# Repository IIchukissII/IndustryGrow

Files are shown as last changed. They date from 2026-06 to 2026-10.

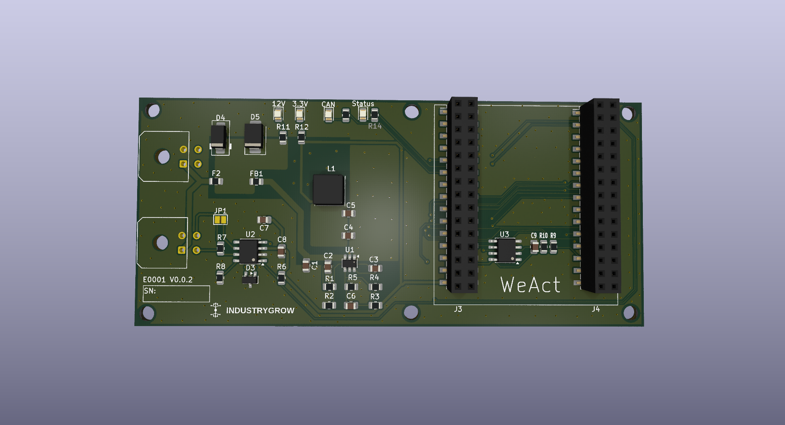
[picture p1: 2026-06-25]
store/E0001-000003-D.png

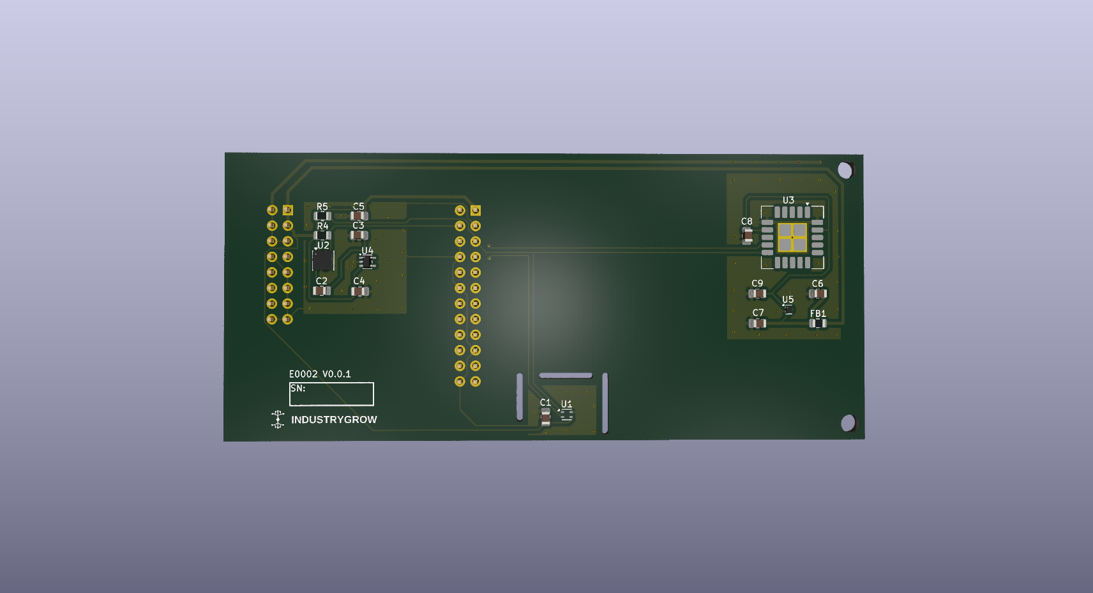
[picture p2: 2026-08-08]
store/E0002-000001-D.png

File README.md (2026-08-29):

<!--
SPDX-FileCopyrightText: 2026 The IndustryGrow contributors
SPDX-License-Identifier: CC-BY-SA-4.0
-->

<picture>
  <source media="(prefers-color-scheme: dark)" srcset="img/industrygrow-logo-mono-dark.svg" />
  IndustryGrow
</picture>

# IndustryGrow



Open-core field hardware, firmware and edge software for instrumented, profile-driven crop
cultivation. One architecture, from a cabinet to a several-hundred-square-metre facility. The
companion platform **IndustryFlow** stores history, runs analytics and distributes profiles.

Scope and rationale: [`MOTIVATION.md`](MOTIVATION.md), [ADR-0001](ADR/ADR-0001-industrygrow-framing.md).

## Architecture constraints

| Constraint | Record |
|---|---|
| Scaling multiplies node *instances* across zones. It adds no node classes. | ADR-0014 d2 |
| A signed, versioned JSON cultivation profile is the only channel that changes deployment behaviour. There is no remote-command API and no real-time tuning channel. | ADR-0015 d1, ADR-0025 |
| The gateway runs control loops locally against a cached profile. The cloud supplies profiles and observes; it does not command in real time. | ADR-0015 d8, ADR-0004 rev 1 |
| The over-temperature trip is analog, MCU- and bus-independent, and sits at the heating actuator. Profiles set operating parameters; hardware sets survival parameters. | ADR-0018 d10 |
| Sensor density is a deployment phase, not a fixture: dense during the empirical survey, reduced for the operating phase. The profile carries the identified model with the setpoints. | ADR-0016 |

## Technology

| Layer | Choice |
|---|---|
| Field bus | Cyphal over classic CAN @ 500 kbit/s, linear topology |
| Smart-node MCU | WeAct STM32F4 64-pin core board (STM32F405RGT6; F412/F446 drop-in) |
| Node carrier PCB | Custom integration board: CAN transceiver, ATECC608 secure element, two-header sensor-module interface |
| Node firmware | Embedded C with libcanard. One application holds every module personality; the module-ID strap selects at boot |
| Node flash layout | Bootloader at the reset vector plus the application in one of two slots; build output is `igrowboot.hex`, `igrow-a.hex`, `igrow-b.hex` |
| Firmware update | Signed image served over the bus, `uavcan.file.Read` to the slot that is not running, trial boot with fallback |
| Gateway | Raspberry Pi (3B+ minimum, 4/5 for higher traffic) + isolated 2-channel CAN HAT |
| Gateway software | Python / asyncio, SocketCAN + Pycyphal + Nunavut-generated DSDL bindings |
| Cloud link | mTLS to IndustryFlow; stateless edge in steady state, with a bounded local store for buffering and survey |
| Identity | Module class from the ID strap, `unique_id` from the ATECC608, Node-ID from a carrier-resident store; 127 = unprovisioned |
| Security | Operator CA, signed firmware, signed profiles |

Governing records: ADR-0002 rev 3 (bus, carrier, gateway), ADR-0005 (DSDL), ADR-0020
(persistence), ADR-0027 (identity), ADR-0029 (update and bootloader), ADR-0024 / ADR-0025 (CA,
profile signing).

> PCBs are authored in **KiCad 10** and will not open in earlier versions; cabinet distribution
> schematics (`E0007`) use **QElectroTech**. Design files live in `store/` under the ADR-0017
> scheme, packaged per document layer as `Exxxx-VVVVVV-S-src.zip` / `-D-src.zip` (d19).
> [`CONTRIBUTING.md`](CONTRIBUTING.md) has the unpack/repack procedure.

## Hardware

Seven sensor-module classes (M01–M07), one functional subsystem each, on the universal carrier
`E0001`, in the cabinet distribution case `E0007`. Instances of one design are specialized by
populated BOM, never by new designs; a functional group fitted or omitted at build is a populate
variant with its own assembly E-number (ADR-0017 rev 2 d4).

E-numbers, sensor complement, module-ID straps, variant rules and per-design state:
[`REGISTRY.md`](REGISTRY.md).

## Status

Phase 1 is data collection only, no actuators; it ends at stage 4, full cabinet telemetry from
M01–M05. Stage sequencing, dependencies, the Phase 1 → Phase 2 boundary and the v1.0 exit
criteria: [`project/ROADMAP.md`](project/ROADMAP.md), 14 dependency-ordered stages.

## Repository

| Path | Contents | Records |
|---|---|---|
| [`ADR/`](ADR/) | Architecture decision records — the source of truth — plus [`GLOSSARY.md`](ADR/GLOSSARY.md) | ADR-0000 |
| [`REGISTRY.md`](REGISTRY.md) | E-number / SP-number identifier map, machine-readable | ADR-0017, ADR-0019, ADR-0023 |
| [`store/`](store/) | Hardware design sources, fab packages and firmware release artifacts, flat, keyed by identifier | ADR-0017 |
| [`spec/`](spec/) | Module specifications — M01, M02, M05, M06, M07. M03 and M04 not yet written | ADR-0014 |
| [`firmware/`](firmware/) | Node firmware (C, libcanard) and the `industryflow.greenhouse` DSDL vocabulary | ADR-0005, ADR-0029 |
| [`gateway/`](gateway/) | Gateway provisioning, hardening, identity and profile-pull client | ADR-0004, ADR-0015 |
| [`erp/`](erp/) | Instance-and-integration ERP — the pre-cloud system of record | ADR-0021, ADR-0022 |
| [`pki/`](pki/) | Operator CA bootstrap and root-key ceremony | ADR-0024 |
| [`signing/`](signing/) | Profile signing tool and runbook | ADR-0025 |
| [`profiles/`](profiles/) | Cultivation profile instances | ADR-0003 |
| [`project/`](project/) | `ROADMAP.md` stage plan, `RESEARCH.md` open directions L1–L7 | — |
| [`MOTIVATION.md`](MOTIVATION.md) | The gap this project closes | — |
| [`CONTRIBUTING.md`](CONTRIBUTING.md) | Contribution licensing, DCO sign-off, working with the store | — |

## Build and run

Firmware — three images, ARM cross-toolchain and Ninja required:

```sh
firmware/tools/bootstrap.sh            # pin submodules; needs nnvg (Nunavut)
cmake -S firmware -B firmware/build -G Ninja \
      -DCMAKE_MAKE_PROGRAM="$(command -v ninja)" \
      -DCMAKE_TOOLCHAIN_FILE="$PWD/firmware/cmake/arm-none-eabi.cmake"
cmake --build firmware/build
```

ERP — application plus operator console:

```sh
cd erp && docker compose up --build    # app on 127.0.0.1:8021
```

Gateway — runs on the Pi, post-first-boot, idempotent:

```sh
sudo ./provision.sh                    # from the staged gateway/ bundle
```

Per-component detail, flashing procedure and signing keys are in each directory's `README.md`.

## Licensing

Open-core, licensed per part of the repository. [`LICENSE.md`](LICENSE.md) is the authoritative
mapping — hardware designs, documentation, application code and the DSDL protocol layer carry four
different licences, and directory-level assumptions do not hold. Full texts are in
[`LICENSES/`](LICENSES/).

Third-party content keeps its own terms, annotated in [`REUSE.toml`](REUSE.toml): the WeAct
core-board snapshot is published with **no licence stated**, so it is not covered by this project's
licences. Compliance is CI-enforced — run `reuse lint` before opening a pull request.

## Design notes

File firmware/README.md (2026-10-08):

<!--
SPDX-FileCopyrightText: 2026 The IndustryGrow contributors
SPDX-License-Identifier: CC-BY-SA-4.0
-->

# IndustryGrow node firmware

Firmware for the IndustryGrow Cyphal/CAN sensor nodes. One codebase, one carrier (`E0001`), one
MCU (STM32F405RGT6 on a WeAct STM32F4 64-Pin Core Board, ADR-0002 rev 3). **One application
image** per carrier revision holds every module personality; the module class ID selects among
them at boot (ADR-0017 rev 2 d16). A node carries two components: a bootloader at the reset vector and that
application in one of two slots (ADR-0029 d1). Sources are `AGPL-3.0-or-later` (ADR-0002 d5); this document is
`CC-BY-SA-4.0`.

## State

| Item | State |
|---|---|
| M05-SAFETY (`E0006`) | Verified on hardware; seven subjects publish (4096–4102) |
| M01-CLIMATE (`E0002`) | Verified on hardware 2026-08-24; ten subjects publish (4112–4121) |
| M02-LIGHT (`E0003`) | Written against the datasheets; four subjects (4128–4131). **No hardware — nothing in M02 spec §11 is executed** |
| M04-PLANT (`E0005`) | Written against the datasheet; one subject (4144) plus an interval frame served over `uavcan.file.Read`. **No hardware — nothing in M04 spec §11 is executed** |
| A01-CLIMATE (`E0011`) | Written against the datasheets and the `E0011-000001` netlist; eleven subjects (4352–4362), six demand subscriptions (4368–4373). Selected only by an `E0001-000100` image. **No hardware — nothing in A01 spec §11 is executed** |
| `E0001-000100` image | Class ID read from the module EEPROM, strap fallback (E0001 spec `F2`–`F5`). Node-ID from the carrier EEPROM `U4` at `0x57` (`F8`). **No hardware — `V9` not executed** |
| Node-ID store (ADR-0027) | Built; verified on hardware 2026-08-28 |
| U3 temperature offset | Implemented as vendor command 3; applied per instance `-CC` (ADR-0028) |
| Boot chain (ADR-0029) | Verified on hardware 2026-08-29: hand-over, fallback, update-state write |
| Firmware download over CAN | Built — the bootloader is a Cyphal node and a `uavcan.file.Read` client |
| Image signing (ADR-0029 d6) | Built — needs a key given to the build; an unsigned image is refused |
| Released `store/E0001-000001-F-*` | All four personalities; **unsigned** — flashes over SWD, refused over the bus. Rebuild with `tools/release.sh --key` before any over-the-air use |
| Subject-ID registers (ADR-0005 d7) | Not implemented — defaults are compiled in |
| SCD41 forced recalibration | Not implemented (M01 spec O-5) |

## What the firmware is

A Cyphal/CAN node. Application protocol and wire vocabulary are fixed elsewhere.

- **Bus** — classic CAN, 500 kbit/s, linear; Node-ID provisioned per instance (ADR-0002 d8,
  ADR-0005 d6, ADR-0027).
- **Vocabulary** — DSDL: the OpenCyphal standard `uavcan.*` set plus project
  `industryflow.greenhouse.*` types (ADR-0005). Physical quantities ride `uavcan.si.sample.*`;
  accumulated S0 energy is joule (ADR-0005 rev 1 d3); door and leak are minimal `safety` status
  types with no command field (M05 is sense-only, ADR-0018 d9).
- **Identity** — three values from three sources, none standing in for another (ADR-0027 d9).
  Module *class* at boot from the ID straps on `E0001-000003`, from byte 0 of the module EEPROM on
  `E0001-000100` (ADR-0014 rev 4 d6, d8). Cyphal `unique_id` from the
  ATECC608 serial, STM32 factory UID as fallback (ADR-0027 d8). *Node-ID* from the store
  below. Role and zone are gateway-side tags, not firmware (ADR-0014 rev 6 d7).

## Toolchain

| Concern | Choice |
|---|---|
| Cyphal transport | [libcanard](https://github.com/OpenCyphal/libcanard) (MIT) |
| Allocator | [o1heap](https://github.com/pavel-kirienko/o1heap) (MIT) |
| DSDL → C | [Nunavut](https://github.com/OpenCyphal/nunavut), pinned via pip, run at build time; generated code not vendored (ADR-0005 d10) |
| Standard types | [public_regulated_data_types](https://github.com/OpenCyphal/public_regulated_data_types), pinned |
| MCU peripherals | CMSIS device headers + register-level init; no vendored HAL tree |
| Compiler / build | `arm-none-eabi-gcc` + CMake |
| Dependency vendoring | git submodules pinned to tags (`tools/bootstrap.sh`) |

## Layout

The **carrier `E0001` is the parent**: `common/carrier/` owns the bus, LEDs, MCU socket and node
identity shared by every node. A **node `nodes/<type>/` is a child**: it carries a module class ID
and adds its sensor or actuator personality. M03 becomes a sibling `nodes/`, adding one line to
`nodes/registry.c`.

```
firmware/
├── README.md  CMakeLists.txt      ← three targets: igrowboot.elf, igrow-a.elf, igrow-b.elf
├── cmake/      arm-none-eabi.cmake (toolchain) · dsdl.cmake (Nunavut codegen)
├── ldscripts/  STM32F405RGTx_BOOT.ld · STM32F405RGTx_APP.ld.in (per-slot template)
├── boot/       main.c update.c verify.c
│                                   ← bootloader: A/B decision, slot check, hand-over;
│                                     the download, and P-256 verification before a
│                                     slot is marked bootable
├── common/                       ← runs identically whichever module is fitted
│   ├── node/       main.c node.h  ← boot → strap → personality dispatch; the seam
│   ├── carrier/    e0001.{h,c}    ← E0001 carrier: pins, LEDs, straps, ATECC608/identity
│   ├── platform/   clock.{h,c}    ← 168 MHz clock, SysTick, micros
│   │               partition.h image.{h,c} update_state.{h,c} crc32.{h,c}
│   │               sha256.{h,c}   ← the ADR-0029 flash map, shared by both images
│   ├── drivers/    can i2c uart   ← bxCAN, I2C1, debug UART (register-level)
│   │               onewire pwm    ← header 1-Wire (PA0) and PWM_1–PWM_4 (TIM3)
│   └── cyphal/     cyphal registers ← Heartbeat/GetInfo/register/ExecuteCommand
├── nodes/
│   ├── registry.c                ← module-ID → personality table (the ONLY file
│   │                                that knows every node type)
│   ├── m05_safety/
│   │   ├── module_id.h (0x05)  sensors.{h,c}
│   │   └── drivers/  ina226 tmp117 s0 leak
│   ├── m01_climate/
│   │   ├── module_id.h (0x01)  sensors.{h,c}
│   │   └── drivers/  sht4x bme68x scd4x · sensirion (shared CRC-8/word codec)
│   ├── m02_light/
│   │   ├── module_id.h (0x02)  sensors.{h,c}
│   │   └── drivers/  tca9543a (bus switch) as7343 tsl2585
│   └── m04_plant/
│       ├── module_id.h (0x04)  sensors.{h,c}
│       │   frame.{h,c} (accumulation + served file) flatfield.{h,c} (the trim)
│   │   └── drivers/  mlx90640 (imager) m24c64 (trim store U2)
│   └── a01_climate/
│       ├── module_id.h (0x80)  actuators.{h,c}
│       │   condition.{h,c} (dead band, dwell, slew, derates)
│       └── drivers/  pca9685 (drive expansion U9) ds18b20 (U1–U4)
├── dsdl/industryflow/greenhouse/
│   ├── safety/    DoorStatus, LeakStatus
│   ├── actuator/  Demand, ElementState, InterlockState
│   ├── climate/   RelativeHumidity, Co2Concentration, GasResistance
│   ├── light/     SpectralSample, PhotonFluxDensity, Irradiance, FlickerStatus
│   └── plant/     CanopyThermalSummary
├── third_party/                  ← submodules: libcanard, o1heap, cmsis, regulated types,
│                                     micro-ecc (BSD-2-Clause; P-256 verification)
└── tools/                        ← bootstrap.sh, release.sh, mkimage.py
```

Pin assignments are not repeated here; `store/E0001-000003-D-pinmap.md` is the BSP source of truth.

## Identity resolution

A strap value no personality claims is **unidentified**, never a guessed class (ADR-0014 rev 6 d6).
The node still brings up the Cyphal skeleton and enumerates as
`org.industrygrow.node.unidentified`, publishing no subjects.

`127` means one thing: no Node-ID provisioned (ADR-0027 d10). An unidentified but provisioned node
keeps its Node-ID and reports the unresolved personality through `GetInfo` and its health.
Publishing requires both a provisioned identity and a resolved personality.

### Provisioning a Node-ID

On `E0001-000003` the store is the last flash sector (`0x080E0000`, sector 11), reserved by the
linker script and outside the application region. On `E0001-000100` it is the carrier EEPROM `U4`
at `0x57` on the header I²C, word address 0 (ADR-0027 d11, E0001 spec `F8`); the flash sector is
not read there. A record is magic, version, Node-ID and CRC; an absent or interrupted record, or a
`U4` that does not answer, reads as unprovisioned.

| Step | Effect |
|---|---|
| Write `uavcan.node.id` = *n* (0–126) | Record rewritten. The register reads *n* while the transport still runs on the old value |
| Restart | *n* is adopted |
| Write `uavcan.node.id` = 127 | Store cleared; the node returns to unprovisioned |

An out-of-range value or a write failure leaves the register reading what the store holds, which is
how a rejected write is visible. While a committed value differs from the running one, the node
repeats a `uavcan.diagnostic.Record` naming it (ADR-0027 d5).

**A flashing tool must not mass-erase.** Writing an image erases only the sectors it covers, and
the store is not one of them (ADR-0027 d4, ADR-0029 d1). A mass erase de-provisions every node it
touches on `E0001-000003`; on `E0001-000100` the identity stays with the carrier's `U4`.

On `E0001-000003` the commit blocks for the sector erase — of the order of a second, interrupts
masked. The erase routine runs from RAM and reloads the watchdog itself, because the flash
controller stalls every flash read while it works; `millis()` loses that interval.

## Default subject-ID map

Compiled-in defaults in the unregulated range. M05 holds 4096–4102, tabled in
`store/E0006-000001-M-bringup-protocol.md`; M01 starts at 4112 and M02 at 4128, each block
leaving the one before it room to grow.

| ID | M01 subject | Source | Type |
|----|---|---|---|
| 4112 | air temperature | U1 SHT45 | `uavcan.si.sample.temperature.Scalar` (K) |
| 4113 | air relative humidity | U1 SHT45 | `…climate.RelativeHumidity` (ratio) |
| 4114 | air VPD | derived from U1 | `uavcan.si.sample.pressure.Scalar` (Pa) |
| 4115 | CO₂ | U3 SCD41 | `…climate.Co2Concentration` (mole fraction) |
| 4116 | barometric pressure | U2 BME688 | `uavcan.si.sample.pressure.Scalar` (Pa) |
| 4117 | gas resistance (VOC trend) | U2 BME688 | `…climate.GasResistance` (Ω) |
| 4118 | secondary temperature | U2 BME688 | `uavcan.si.sample.temperature.Scalar` (K) |
| 4119 | secondary humidity | U2 BME688 | `…climate.RelativeHumidity` (ratio) |
| 4120 | secondary temperature | U3 SCD41 | `uavcan.si.sample.temperature.Scalar` (K) |
| 4121 | secondary humidity | U3 SCD41 | `…climate.RelativeHumidity` (ratio) |

| ID | M02 subject | Source | Type |
|----|---|---|---|
| 4128 | spectral counts, 12 bands + clear | U4 AS7343 | `…light.SpectralSample` (counts + settings) |
| 4129 | PPFD | derived from U4 | `…light.PhotonFluxDensity` (mol·m⁻²·s⁻¹) |
| 4130 | flicker flags | U4 AS7343 | `…light.FlickerStatus` |
| 4131 | UV-A irradiance | U3 TSL2585 | `…light.Irradiance` (W·m⁻²) |

| ID | M04 subject | Source | Type |
|----|---|---|---|
| 4144 | canopy thermal summary, 32×24 field | U1 MLX90640, derived | `…plant.CanopyThermalSummary` (K) |

4132 and 4133 were UV-B and UV-C and are **retired, not reassigned** (ADR-0014 rev 6): nothing
may bind a new quantity to either. 4129 carries a `valid` flag because PPFD needs commissioning
coefficients the node does not have until they are written (M02 spec 6.2, O-52).

M04 publishes statistics, not the field: the 768-pixel frame is served over `uavcan.file.Read` at
`/plant/frame.bin`, one interval frame per minute, and the record announces it through `frame_seq`
and `frame_available` (ADR-0005 d11, d12). Its flat-field trim arrives the other way, over
`uavcan.file.Write` at `/plant/flatfield.bin`, and is committed to the module's own EEPROM bound to
the imager's device ID (ADR-0028 d10).

| ID | A01 subject | Source | Type |
|----|---|---|---|
| 4352 | WB1 block temperature | U1 DS18B20 | `uavcan.si.sample.temperature.Scalar` (K) |
| 4353 | main exchanger base temperature | U2 DS18B20 | `uavcan.si.sample.temperature.Scalar` (K) |
| 4354 | subcooler coil base temperature | U3 DS18B20 | `uavcan.si.sample.temperature.Scalar` (K) |
| 4355 | reheater base temperature | U4 DS18B20 | `uavcan.si.sample.temperature.Scalar` (K) |
| 4356–4361 | applied demand and drive state, `E1`–`E6` | firmware | `…actuator.ElementState` |
| 4362 | interlock lines `T2`–`T5`, now and latched | `GPIO_1`–`GPIO_4` | `…actuator.InterlockState` |
| 4368–4373 | demand, `E1`–`E6` (subscribed) | gateway | `…actuator.Demand` |

A temperature publishes only once its DS18B20 ROM code is written to `a01.ow.rom`
(U1–U4, `natural64[4]`); vendor command 1 lists the codes the boot search found. `E6` neither
subscribes nor publishes until `a01.valve` marks the valve fitted (A01 spec `F12`). The other
commissioning registers are `a01.drive`, `a01.thermal`, `a01.fan` and `a01.e1.heat_ph`,
defaulting to the specification's values. **None persists across power-up** (ADR-0005 d7).

Only 4112–4114 are admissible for VPD and the climate control loop. 4118–4121 are the secondary
sources of M01 spec §4; 4120 and 4121 are valid for an instance once its `-CC` is filed (O-45,
ADR-0028 d9).

## Build

`CMAKE_TOOLCHAIN_FILE` must be **absolute**, and the Ninja generator needs `CMAKE_MAKE_PROGRAM`
given explicitly — a relative toolchain path fails with *"Could not find toolchain file"*.

```sh
tools/bootstrap.sh                     # fetch and pin submodules; needs nnvg (Nunavut)

cmake -S firmware -B firmware/build -G Ninja \
      -DCMAKE_MAKE_PROGRAM="$(command -v ninja)" \
      -DCMAKE_TOOLCHAIN_FILE="$PWD/firmware/cmake/arm-none-eabi.cmake"
cmake --build firmware/build
```

The image is built for one carrier revision, `-DIGROW_CARRIER_REV=000003` (the default) or
`000100` (E0001 spec `F1`). Only a `000100` image reaches an actuator class, because no strap
carries `0x80`.

Both settings are cached, so later configures may pass only `-DCMAKE_BUILD_TYPE=`. Release is much
smaller than Debug (~21 KB against ~66 KB). Linker warnings from `nosys.specs` (`_close is not
implemented`, `LOAD segment with RWX permissions`) are expected.

Output is three images. What a node becomes is decided by the module in the carrier socket, not by
which file was flashed; which slot an application image is for is a link address, not a variant.

| Artifact | Load address | Holds |
|---|---|---|
| `igrowboot.hex` | `0x08000000` | bootloader, sectors 0–3 |
| `igrow-a.hex` | `0x08020000` | image header + application, slot A |
| `igrow-b.hex` | `0x08080000` | image header + application, slot B |
| `igrow-<slot>.img` | — | the same bytes unaddressed: what a signature covers and what the gateway serves |

`tools/mkimage.py` writes the header (`common/platform/image.h`); the flash map it addresses is
ADR-0029 d1, stated in C by `common/platform/partition.h`.

### Signing keys

An image is accepted over the bus only if it carries a signature from the key the bootloader was
built with (ADR-0029 d6). Neither half of that key lives in this repository — custody is the key
ceremony's (ADR-0024) — so both are build inputs:

```sh
py tools/mkimage.py --new-key ~/igrow-signing-key.pem      # once, kept off the repo
py tools/mkimage.py --public-key ~/igrow-signing-key.pem   # prints 128 hex characters

cmake -S firmware -B firmware/build ... \
      -DIGROW_SIGNING_KEY="$HOME/igrow-signing-key.pem" \
      -DIGROW_VERIFY_KEY_HEX=<those 128 characters>
```

Give both or neither: CMake refuses half a pair, because a bootloader holding a key its images are
not signed with rejects every one of them. Without either, the build still runs and the images
still flash over SWD; they simply cannot be accepted over the bus. The build says so at configure
time, and **the bootloader says so at boot** — `verification key present` or `ABSENT`.

`tools/release.sh` takes `--key <pem>` or `--unsigned` and refuses to guess. It builds in its own
directory (`firmware/build-release`), so a release never resets the keys cached in the tree you
flash from.

## Flashing and updating

First flash over SWD, then updates over CAN

SWD is on the WeAct debug header, reachable with the carrier mounted. CAN1 sits on PB8/PB9, off the
USB pins, so WeAct USB DFU stays available as a recovery path (pin-map note 5).

| | Command |
|---|---|
| First flash, 1 | `STM32_Programmer_CLI -c port=SWD mode=UR freq=950 -d E0001-VVVVVV-F-boot.hex -v` |
| First flash, 2 | `STM32_Programmer_CLI -c port=SWD mode=UR freq=950 -d E0001-VVVVVV-F-slot-a.hex -v` |
| Provision | `store/SP0004-M-gateway-bringup.md` §8 |
| Update | `uavcan.node.ExecuteCommand` 65533, artifact path in the parameter |

Whoever sends the command serves the file: the bootloader reads it back from that node with
`uavcan.file.Read` (subject 408). The target is always the slot that is not running.

| Blue LED (PB2) | Node is |
|---|---|
| dark | running the application |
| lit | in the bootloader, on the bus |
| flickering | downloading, one flicker per 256-byte block |
| steady through a pause | verifying |
| 2 Hz | holding no bootable image, waiting for one |

A failed download clears the request before erasing anything, so a node that cannot reach its file
server retries nothing and boots what it already had.

## Release artifacts (`store/`)

`tools/release.sh` builds the image and publishes it under the ADR-0017 rev 2 **`F` (Firmware)**
document layer (see `REGISTRY.md`):

```
store/E0001-000001-F-boot.hex    # bootloader
store/E0001-000001-F-slot-a.hex  # application, slot A
store/E0001-000001-F-slot-b.hex  # application, slot B
store/E0001-000001-F-slot-a.img  # the same images without a load address:
store/E0001-000001-F-slot-b.img  # what a signature covers, what the bus serves
store/E0001-000001-F-src.zip     # source snapshot of firmware/ at HEAD
```

Filed under `E0001` — the carrier whose one codebase every node runs, so firmware identity follows
the carrier, not the module (ADR-0017 rev 2 d16). One `F` object per firmware version covers every
node type. Refreshed in place at the same `F` version while unverified against hardware; `F` bumps
on a released change. `firmware/build*/` stays git-ignored.

## References

- ADR-0002 rev 3 — field bus: Cyphal/CAN, MCU, carrier, 500 kbit/s.
- ADR-0005 rev 1 — DSDL foundation: vocabulary, joule energy, node skeleton, port-IDs.
- ADR-0014 rev 6 — sensor-node taxonomy: module straps, presence probing, gateway tagging.
- ADR-0007 rev 1 — PKI and hardware identity: the ATECC608 as identity anchor.
- ADR-0017 rev 2 — document layers; d16 roots firmware on the carrier.
- ADR-0029 — node firmware update and bootloader: the flash partition, A/B slots and image header.
- ADR-0018 — M05 sense-only; door/leak report-only; S0 energy.
- ADR-0027 — node identity model: the Node-ID store, its survival and `127`.
- ADR-0028 — commissioning sequence and trim custody.
- `spec/E0002-R-specification.md` — M01 sensor complement, VPD, CO₂ handling, §10.
- `spec/E0006-R-specification.md` — the as-built form of that document class.
- `store/E0001-000003-D-pinmap.md` — carrier pin map, the BSP source of truth.

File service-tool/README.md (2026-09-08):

<!-- SPDX-FileCopyrightText: 2026 The IndustryGrow contributors -->
<!-- SPDX-License-Identifier: AGPL-3.0-or-later -->

# Service tool firmware — `E0010`

Reads the cabinet CAN bus and shows it, executes a carried `-M-` protocol step by
step, and emits the record it does not keep. Requirements, interfaces and
verification are in [`spec/E0010-R-specification.md`](../spec/E0010-R-specification.md);
the role and its bounds are in `ADR/ADR-0030`. Neither is restated here.

Hardware bring-up order, the traps, and what has been measured on each board are
in [`BENCH.md`](BENCH.md).

## What this directory is

Self-contained. Nothing elsewhere in the repository refers to it and the node
firmware build does not build it. The one thing it reaches for is the
vocabulary: `cmake/dsdl.cmake` runs Nunavut over `firmware/dsdl` and
`firmware/third_party/public_regulated_data_types` at build time, so the tool
decodes the same types the nodes publish rather than a second copy that can
drift. `app/subjects.c` holds only the subject-ID to type binding, mirroring
`gateway/files/app/igrow_subjects.py`.

## Targets

One codebase, one `F` root, two build variants (ADR-0017 d16). `-DIGROW_BOARD=`
selects the MCU, the startup file, the BSP, the panel size and the core supply;
`Core/Inc/eval_board.h` is the only file that knows which.

| | `H753` (default) | `H757` |
|---|---|---|
| Board | STM32H753I-EVAL | STM32H757I-EVAL |
| Panel | MB1063, 640x480, LTDC parallel RGB | MB1166, 800x480, DSI |
| Build tree | `build/` | `build-h757/` |

| Image | What |
|---|---|
| `igrow-panel` | the tool: FreeRTOS + LVGL + Cyphal |
| `igrow-min` | bare metal, console first, every wait bounded — for when the panel goes silent |
| `igrow-check` | headless board self-test, no display needed |

## Build

```powershell
powershell -ExecutionPolicy Bypass -File tools\build.ps1                        # H753, all three
powershell -ExecutionPolicy Bypass -File tools\build.ps1 -Board H757            # H757, all three
powershell -ExecutionPolicy Bypass -File tools\build.ps1 -Board H757 -Target igrow-check.elf

powershell -ExecutionPolicy Bypass -File tools\flash.ps1 -Board H757 -Image igrow-check
powershell -ExecutionPolicy Bypass -File tools\mon.ps1 -Port COM4 -Seconds 30
```

`flash.ps1 -Board` selects the probe by serial number: both eval boards present
an ST-LINK-V3E as `VID_0483&PID_374E`, and an image flashed into the wrong MCU is
not a diagnosis.

### Dependencies

| CMake variable | What | Vendored here |
|---|---|---|
| `CUBE_DIR` | STM32CubeH7 — HAL, CMSIS, both EVAL BSPs, components | no |
| `LVGL_DIR` | LVGL 9.2 | no |
| `IGROW_REPO` | this repository — libcanard, o1heap, the DSDL | n/a, defaults to `..` |

STM32CubeH7 and LVGL are large upstream trees and are not vendored. Clone them
and pass `-DCUBE_DIR=` and `-DLVGL_DIR=`, or place them under `deps/`
(gitignored), which is where CMake looks by default. `tools\build.ps1` passes
this bench's own location; it is one line at the top of that file.

`arm-none-eabi-gcc` 12.3 and `STM32_Programmer_CLI` both come from the
STM32CubeIDE 1.16.0 installation; `nnvg` is Nunavut 2.3.1 from the user Python
install. Nothing extra needs installing.

Files retained from STM32CubeH7 and LVGL keep their own terms — see the
third-party section of [`LICENSE.md`](../LICENSE.md).

## Layout

```
app/     can_port      FDCAN, the pin sweep, statistics
         cyphal_rx     libcanard, subscriptions, the two request types
         subjects      subject-ID -> type -> display unit, and the decoders
         model         what has been seen: nodes, signals, 240-sample histories
         protocol      the carried -M- procedure, its executor and the emitted record
         console       USART1 text output; the whole UI when there is no display
         panel_mem     the hand-partitioned SDRAM map
ui/      lvgl_port     display, touch, joystick, LVGL binding
         ui_main       the six tabs and joystick navigation
diag/    min_main      the bare-metal image
         board_check   the headless self-test
Core/    ST template files, both startup files, the linker script, lv_conf.h
```

## Interface

Six tabs — Bus, Liveness, Nodes, Plot, Values, Protocol.

Driven by the MB1246 five-way alone: arrows move, a click on SEL enters, a hold
on SEL goes back. Three levels — tab row, landed in a tab, widget selected — so
entering a tab never lands on a control (`BENCH.md`). The two push-buttons blank and restore the display and take no
part in navigation. Touch is used where the fitted panel has it.

Ground and accents come from `img/industrygrow-logo.svg`: navy `#0A1428` with
the mark's cyan/green family. The four status colours are **not** brand colours
and are never reused as a series colour; they map one to one onto
`uavcan.node.Health`, and every use pairs the colour with a word, so nothing
means anything by colour alone. One signal is plotted at a time, so there is no
categorical palette and no legend. Every mark clears 3:1 against the navy and
every text colour 4.5:1.

If the display does not come up the firmware carries on and reports the same
material as text on the ST-LINK virtual COM port at 115200 8N1.

## Bus parameters

Fixed by ADR-0002 d8 and not configurable here.

| Parameter | Value |
|---|---|
| Format | Classic CAN, `FDCAN_FRAME_CLASSIC`; the tool never emits an FD frame |
| Bit rate | 500 kbit/s |
| Kernel clock | HSE, 25 MHz — not a PLL output, so display retuning cannot move the bit rate |
| Bit timing | Prescaler 2, TSEG1 21, TSEG2 3, SJW 3 → 25 tq, sample point 88 % |
| Node-ID | 10 by default. 1 is the gateway time master, 96 and 97 are the nodes |

The tool joins in **bus monitoring mode** and stays there until somebody presses
a button; in that mode the peripheral does not drive the bus at all, not even the
ACK bit. It publishes no heartbeat.

## Memory

| Region | Address | Contents |
|---|---|---|
| Flash | `0x08000000` | 362 KB of 1024 KB |
| DTCM | `0x20000000` | `.data`, `.bss`, stack |
| AXI SRAM | `0x24000000` | `.axi_bss` — the 48 KB libcanard arena |
| SDRAM | `0xD0000000` | LTDC framebuffer, 4 MB reserved: holds either panel at RGB565 |
| | `0xD0400000` | Two LVGL draw buffers, 120 lines each |
| | `0xD0480000` | LVGL heap, 4 MB |
| | `0xD0900000` | `.sdram_bss` — the model |

The low 9 MB of SDRAM are assigned by address in `app/panel_mem.h` because the
LTDC and LVGL are handed addresses at init, not linker symbols. Static asserts
catch the framebuffer and the heap running into what follows them.

The framebuffer is written by the CPU and read by the LTDC, which does not see
the D-cache, so the MPU maps SDRAM write-through.

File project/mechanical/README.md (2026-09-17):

<!--
SPDX-FileCopyrightText: 2026 The IndustryGrow contributors
SPDX-License-Identifier: CC-BY-SA-4.0
-->

# Mechanical development sources

Mechanical design sources under iteration, outside the document store and carrying no
identifier (ADR-0032 d8, ADR-0017 d5).

| | |
|---|---|
| Contents | One file per part, STEP plus the print-ready geometry |
| Naming | Part name, as the specification names it |
| Versioning | Git history. No version field, no serial, no E- or SP-number |
| Licence | CERN-OHL-S-2.0 (`REUSE.toml`), as `store/**` |
| Exit | At the commit a combination reaches, its parts file under the identifier that commit assigns and leave this directory |

`spec/E0012-R-specification.md` occupies it with the housing HS1 and the §5 duct set — DA1, DT1,
IT1, PL1 and SL1. A01-CLIMATE's humidity tract follows: TB1, the exchanger sections that house
`SP0011`, the wall penetrations and the condensate collector, per `spec/E0011-R-specification.md`
§9.

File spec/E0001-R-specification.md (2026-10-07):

<!--
SPDX-FileCopyrightText: 2026 The IndustryGrow contributors
SPDX-License-Identifier: CC-BY-SA-4.0
-->

# Universal carrier — module specification

- **Status:** `E0001-000003` fabricated and in service; `E0001-000100` ordered, not received
- **Date:** 2026-10-06
- **E-number:** `E0001` · no class ID — the carrier is not a module
- **Governing ADRs:** ADR-0002 (rev 3), ADR-0007 (rev 1), ADR-0014 (rev 4), ADR-0017 (rev 2), ADR-0018, ADR-0027, ADR-0029, ADR-0031 (rev 1)
- **Companions:** every module specification in `spec/`; `store/E0001-000003-D-pinmap.md` for the fabricated revision
- **Supersedes:** nothing

Rationale for the decisions applied here is in the governing ADRs and is not restated.
Values marked `verify` are not confirmed against the manufacturer datasheet.

## 1. Scope

Requirements for the universal carrier: what it hosts, the module-header contract it presents,
the pin assignment of each revision in service, power, firmware and verification. Every module
class mates with this contract and no module specification restates it.

Not specified here:

| Subject | Owner |
|---|---|
| What any module does with a header signal | that module's specification |
| Core-board design | `SP0005`, vendor document in `store/SP0005-D-coreboard-snapshot.zip` |
| Field-bus protocol, bit rate and topology | ADR-0002 rev 3 |
| Node identity, keys and certificates | ADR-0007 rev 1 |
| Cabinet power distribution upstream of the bus connector | ADR-0018 |
| Layout, fabrication outputs and the bill of materials | `store/E0001-VVVVVV-D-*`, `-L.csv` |

## 2. Identification

| | Value |
|---|---|
| E-number | `E0001` — one bare design per revision, one assembly (ADR-0017 d4) |
| Class ID | None. The carrier is the parent of a node and carries no module class |
| Node identity | ATECC608 on the carrier, not on the module (ADR-0007 rev 1) |
| Node-ID store | Flash record at `E0001-000003`; the carrier EEPROM U4 at `E0001-000100` (ADR-0027 d2, d11) |
| Serialized | Yes, per assembly |

### 2.1 Revisions in service

| Revision | Module identification | Header B | State |
|---|---|---|---|
| `E0001-000003` | 3-bit strap pattern on Header B positions 3–5 (ADR-0014 rev 4 d6) | 2×8 | Fabricated, in service |
| `E0001-000100` | 8-bit class ID read from the module's EEPROM over the header I²C at `0x50` (ADR-0014 rev 4 d6) | 2×10 | Ordered, not received (`O-100`) |

Neither supersedes the other. Each carries its own firmware image. An actuator module runs only
on `E0001-000100` (ADR-0031 d10).

## 3. Function

| Function | Realization |
|---|---|
| Host the processor | Two sockets receive the `SP0005` core board |
| Join the field bus | `SN65HVD230` on CAN1, daisy-chained through two identical connectors, termination fitted by a solder jumper |
| Hold the node identity | `ATECC608B` on a private I²C segment, reachable by no module |
| Derive the node rail | `TPS54302` buck, `+12 V` SELV input to 3.3 V |
| Present the module contract | Two sockets carrying the §5 signal set |
| Indicate state | Four indicators: input rail, node rail, bus activity, node status |

![The field bus and the twelve volt supply arrive together on one connector and leave on its twin, so nodes daisy-chain; the supply passes the input protection to the buck, whose output is the only rail the carrier derives and reaches the core board and both module headers; the bus pair reaches the transceiver with its termination jumper and on to the core board, the secure element sits on a second segment no module reaches, everything a module may use crosses the two header sockets, and at the later revision the carrier's own Node-ID store answers on the header bus beside the module's class-ID EEPROM](./figures/e0001-carrier-topology.svg)

### 3.1 Exclusions

| Function | Owner |
|---|---|
| Any measurement | The fitted module |
| Any load switching or actuator drive | The actuator module (ADR-0018 d1, d8) |
| Any rail other than 3.3 V | `SP0003` for `+12 V`, `SP0010` for `+24 V` (ADR-0018 d3) |
| Gateway, bus master, time source | `SP0004` |

## 4. Device complement

| Ref | Device | Function | Rail |
|---|---|---|---|
| U1 | TI TPS54302, SOT-23-6 | 3.3 V buck from the `+12 V` bus, with L1 10 µH | `+12 V` |
| U2 | TI SN65HVD230, SOIC-8 | CAN transceiver on CAN1 | 3V3 |
| U3 | Microchip ATECC608B-SSHDA, SOIC-8 | Secure element on I²C2, node identity (ADR-0007 rev 1) | 3V3 |
| U4 | ST M24C64-RMN6TP, 64 kbit, SO8 | Node-ID store on the header I²C at `0x57`: `E0`–`E2` to 3V3, `WC` to GND. Fitted at `E0001-000100` only, decoupled by C10 100 nF (ADR-0027 d11) | 3V3 |
| F2 | PTC resettable fuse, 0.5 A hold, 16 V, 0805. `E0001-000003` is fitted with 0.35 A hold | Bus-input protection | `+12 V` |
| D4 | SK26AH Schottky | Reverse-polarity protection on the bus input | `+12 V` |
| D5 | SMBJ16A | Transient suppressor on the bus input | `+12 V` |
| FB1 | BLM21P ferrite | Bus-input filter | `+12 V` |
| D3 | PESD1CAN | Transient suppressor on CANH and CANL | — |
| R7, JP1 | 120 Ω across the bus pair, solder jumper | Bus termination, fitted only at the two ends of the run (ADR-0002 rev 3) | — |
| D6–D9 | Indicators: `+12 V`, 3V3, CAN activity, node status | §3 | — |
| J1, J2 | Molex Micro-Fit 3.0, 2×2, horizontal | Field bus and `+12 V`, in and out (ADR-0018 d13) | — |
| J3, J4 | 2×15 sockets, 2.54 mm | Core-board interface (§5.4) | — |
| J5 | 2×12 socket, 2.54 mm | Module Header A | — |
| J6 | 2×8 socket at `E0001-000003`, 2×10 at `E0001-000100` | Module Header B | — |

Every passive on the board belongs to a device above.

Deliberately absent:

| Not fitted | Reference |
|---|---|
| Any sensor. The carrier measures nothing | §3.1 |
| Any switching element. Load switching lives at the actuator | ADR-0018 d1, d8 |
| A 5 V rail. Header A position 2 is present and unconnected | `I5` |

## 5. Interfaces

### 5.1 Module header — the contract

Every module mates through **two** sockets carrying one signal set, whatever its class
(ADR-0014 d5). The sockets are different sizes (`I2`).

| Group | Count | Signals |
|---|---|---|
| Power | 3 | 3V3 at Header A position 1 and Header B position 1; 5 V at Header A position 2, unconnected |
| Ground | 14 at `E0001-000003`, 16 at `E0001-000100` | Interspersed; every analog input flanked |
| I²C | 2 | `I2C_SCL`, `I2C_SDA` — also the transport of the module class-ID EEPROM and, at `E0001-000100`, of U4 |
| SPI | 5 | `SPI_SCK`, `SPI_MISO`, `SPI_MOSI`, `SPI_CS1`, `SPI_CS2` |
| 1-Wire | 1 | `OW_DATA` |
| PWM | 4 | `PWM_1`–`PWM_4`, one timer, independent duty |
| GPIO | 4 at `E0001-000003`, 7 at `E0001-000100` | `GPIO_1`–`GPIO_4`; `GPIO_5`–`GPIO_7` replace the straps |
| ADC | 2 at `E0001-000003`, 4 at `E0001-000100` | `ADC_1`–`ADC_4`, 12-bit, from the processor |
| Module ID | 3 at `E0001-000003`, 0 at `E0001-000100` | `STRAP_0`–`STRAP_2`, tied on the module |
| Reserved | 2 | Header B positions 7 and 14, unconnected at both revisions |

### 5.2 Signal pin assignment

`E0001-000100` differs from `E0001-000003` in five positions and in nothing else. The **Core
board** column gives the position on the `SP0005` headers, P1 (2×12) or P2 (2×13).

| Signal | MCU pin | Function (AF) | Core board | Header | Revision |
|---|---|---|---|---|---|
| CAN_RX | PB8 | CAN1_RX (AF9) | P2.4 | — | both |
| CAN_TX | PB9 | CAN1_TX (AF9) | P2.1 | — | both |
| I2C_SCL | PB6 | I2C1_SCL (AF4) | P2.6 | A.4 | both |
| I2C_SDA | PB7 | I2C1_SDA (AF4) | P2.3 | A.5 | both |
| I2C2_SCL | PB10 | I2C2_SCL (AF4) | P1.24 | — | both, ATECC608 |
| I2C2_SDA | PB11 | I2C2_SDA (AF4) | P1.23 | — | both, ATECC608 |
| SPI_SCK | PB13 | SPI2_SCK (AF5) | P2.26 | A.9 | both |
| SPI_MISO | PB14 | SPI2_MISO (AF5) | P2.23 | A.10 | both |
| SPI_MOSI | PB15 | SPI2_MOSI (AF5) | P2.24 | A.11 | both |
| SPI_CS1 | PA3 | GPIO output | P1.14 | A.13 | both |
| SPI_CS2 | PA4 | GPIO output | P1.13 | A.14 | both |
| GPIO_1 | PA9 | GPIO, also USART1_TX | P2.18 | A.15 | both |
| GPIO_2 | PA10 | GPIO, also USART1_RX | P2.15 | A.16 | both |
| GPIO_3 | PA15 | GPIO, JTDI at reset | P2.14 | A.17 | both |
| GPIO_4 | PB12 | GPIO | P2.25 | A.18 | both |
| PWM_1 | PC6 | TIM3_CH1 (AF2) | P2.21 | A.20 | both |
| PWM_2 | PC7 | TIM3_CH2 (AF2) | P2.22 | A.21 | both |
| PWM_3 | PB0 | TIM3_CH3 (AF2) | P1.19 | A.22 | both |
| PWM_4 | PB1 | TIM3_CH4 (AF2) | P1.22 | A.23 | both |
| OW_DATA | PA0 | GPIO open-drain | P1.9 | A.7 | both |
| LED_STATUS | PA1 | GPIO output | P1.12 | — | both |
| LED_CAN | PA2 | GPIO output | P1.11 | — | both |
| ADC_1 | PC4 | ADC12_IN14 | P1.17 | B.10 | both |
| ADC_2 | PC5 | ADC12_IN15 | P1.20 | B.12 | both |
| STRAP_0 | PA5 | GPIO input | P1.16 | B.3 | `E0001-000003` |
| STRAP_1 | PA6 | GPIO input | P1.15 | B.4 | `E0001-000003` |
| STRAP_2 | PA7 | GPIO input | P1.18 | B.5 | `E0001-000003` |
| GPIO_5 | PA5 | GPIO | P1.16 | B.3 | `E0001-000100` |
| GPIO_6 | PA6 | GPIO | P1.15 | B.4 | `E0001-000100` |
| GPIO_7 | PA7 | GPIO | P1.18 | B.5 | `E0001-000100` |
| ADC_3 | PC0 | ADC123_IN10 | P1.5 | B.17 | `E0001-000100` |
| ADC_4 | PC1 | ADC123_IN11 | P1.8 | B.19 | `E0001-000100` |
| SWDIO | PA13 | SWDIO (AF0) | — | — | both, core-board debug header |
| SWCLK | PA14 | SWCLK (AF0) | — | — | both, core-board debug header |

Unassigned processor pins:

| Pin | Core board | Reserve for |
|---|---|---|
| PC2 | P1.7 | A further analog channel |
| PC3 | P1.10 | A further analog channel |
| PB3 | — | Any signal; also JTDO / SWO |
| PB4 | — | Any signal |
| PB5 | — | Any signal |

### 5.3 Header pinout

| Position | Header A, 2×12 | Header B, `E0001-000003`, 2×8 | Header B, `E0001-000100`, 2×10 |
|---|---|---|---|
| 1 | 3V3 | 3V3 | 3V3 |
| 2 | 5V, unconnected | GND | GND |
| 3 | GND | `STRAP_0` | `GPIO_5` |
| 4 | `I2C_SCL` | `STRAP_1` | `GPIO_6` |
| 5 | `I2C_SDA` | `STRAP_2` | `GPIO_7` |
| 6 | GND | GND | GND |
| 7 | `OW_DATA` | RESERVED | RESERVED |
| 8 | GND | GND | GND |
| 9 | `SPI_SCK` | GND | GND |
| 10 | `SPI_MISO` | `ADC_1` | `ADC_1` |
| 11 | `SPI_MOSI` | GND | GND |
| 12 | GND | `ADC_2` | `ADC_2` |
| 13 | `SPI_CS1` | GND | GND |
| 14 | `SPI_CS2` | RESERVED | RESERVED |
| 15 | `GPIO_1` | GND | GND |
| 16 | `GPIO_2` | GND | GND |
| 17 | `GPIO_3` | — | `ADC_3` |
| 18 | `GPIO_4` | — | GND |
| 19 | GND | — | `ADC_4` |
| 20 | `PWM_1` | — | GND |
| 21 | `PWM_2` | — | — |
| 22 | `PWM_3` | — | — |
| 23 | `PWM_4` | — | — |
| 24 | GND | — | — |

### 5.4 Core-board interface

| Socket | Receives | Spans |
|---|---|---|
| J3, 2×15 | `SP0005` P1 and the 3V3 power header below it | 12 signal rungs plus 3 power rungs |
| J4, 2×15 | `SP0005` P2 and the 5 V power header below it | 13 signal rungs plus 2 power rungs |

### 5.5 Interface requirements

| ID | Requirement | Reference |
|---|---|---|
| `I1` | Both module sockets carry the §5.1 signal set at every revision. A revision adds positions; it never moves or repurposes one already assigned | ADR-0014 d5 |
| `I2` | The two module sockets differ in size at every revision, so a module cannot be seated rotated | ADR-0014 d5 |
| `I3` | A module built to an earlier Header B seats on positions 1–16 of the wider socket and does not reach beyond | §5.3 |
| `I4` | Header B positions 7 and 14 stay unconnected until a revision assigns them | §5.1 |
| `I5` | Header A position 2 is present and unconnected; no revision fits a 5 V rail without its own specification change | §4 |
| `I6` | Every analog input on Header B is flanked by ground, and no switching signal shares Header B | ADR-0014 d5 |
| `I7` | Bus termination is fitted by `JP1` only at the two ends of the run | ADR-0002 rev 3 |
| `I8` | SWD reaches the processor on the core board's own debug header; the carrier routes neither line | §5.2 |
| `I9` | U4 answers at `0x57` and a fitted module's class-ID EEPROM at `0x50`, both on the header I²C. No module places another device inside `0x50`–`0x57` | ADR-0027 d11, ADR-0014 rev 4 d6 |

## 6. Power

| ID | Requirement | Reference |
|---|---|---|
| `P1` | Input is the `+12 V` SELV bus, fused at 0.5 A, reverse-protected, transient-suppressed and filtered before the buck | ADR-0018 d3 |
| `P2` | The carrier derives 3.3 V locally and is the only source of the module rail. No module derives its own | ADR-0002 rev 3 |
| `P3` | 3.3 V reaches the core board through the power rungs of J3, and reaches each module at both header position 1 | §5.4 |
| `P4` | The core board is powered from the carrier **or** from its own USB, never both | `SP0005` |
| `P5` | Carrier and module current on the 3.3 V rail is bounded by the buck's rating (`verify` against the fitted inductor and thermal design) | `O-132` |
| `P6` | No actuator load is taken from the `+12 V` bus or the 3.3 V rail | ADR-0018 d3 |

## 7. Firmware requirements

| ID | Requirement | Reference |
|---|---|---|
| `F1` | Each revision runs its own image; an image identifies the revision it was built for | §2.1 |
| `F2` | On `E0001-000100`, probe the module EEPROM at `0x50` first. A module that answers is identified by byte 0 and its `GPIO_5`–`GPIO_7` are never read as an identity | ADR-0014 rev 4 d6 |
| `F3` | `0x00` and `0xFF` are *unidentified*, never a class | ADR-0014 rev 4 d6 |
| `F4` | On `E0001-000100`, a module that does not answer at `0x50` may be identified by the legacy strap pattern on `GPIO_5`–`GPIO_7` | §2.1 |
| `F5` | `GPIO_5`–`GPIO_7` are configured as inputs at reset and driven only after identification, because a module may hold them against a rail | `F4` |
| `F6` | The node publishes its heartbeat and health over the field bus; the carrier publishes no measured quantity | §3.1 |
| `F7` | `GPIO_1` and `GPIO_2` carry USART1. A bench console is available only while no fitted module claims them, and the module wins | §5.2 |
| `F8` | At `E0001-000100` the Node-ID is the record U4 holds — magic, version, Node-ID, CRC — and the class ID is never read as an instance identity. At `E0001-000003` the same record is held in flash | ADR-0027 d2, d9, d11 |

## 8. Verification

| ID | Verifies | Method |
|---|---|---|
| `V1` | `I1`, `I2`, `I4`, `I5`, `I6` | Continuity-check every header position against §5.3 on a bare board; confirm the two sockets differ in size, and that Header B positions 7 and 14 and Header A position 2 reach no net |
| `V2` | `I3` | Seat a module built to the earlier Header B on the wider socket; confirm every signal it uses reads correctly |
| `V3` | `I7` | Measure across the bus pair with `JP1` open and closed; confirm 120 Ω only when closed |
| `V4` | `I8` | Attach a debugger to the core-board header with the carrier mounted; confirm it halts the processor |
| `V5` | `P1`, `P2`, `P4`, `P6` | Apply reversed input at the bus connector and confirm no current passes. Measure the 3.3 V rail at both header position 1. Power the core board from the carrier and from USB in turn, never both, and confirm the rail in each case |
| `V6` | `P3`, `P5` | Load the 3.3 V rail to the `P5` bound for 1 h; record the buck case temperature and the rail's droop |
| `V7` | `F1`, `F2`, `F3`, `F4` | Present in turn a module with a programmed EEPROM, one reading `0xFF`, and one with only a strap pattern; confirm the identity each yields, and that the image reports the revision it was built for |
| `V8` | `F5`, `F6`, `F7` | Hold `GPIO_5`–`GPIO_7` against both rails through a module and confirm no carrier output opposes them at reset. Enumerate every subject the node publishes and confirm no measured quantity is among them. Open a console on USART1 with no module fitted, then seat one that claims `GPIO_1`, and confirm the console stops |
| `V9` | `I9`, `F8` | Address-scan the header I²C with a module seated; confirm U4 and the module EEPROM answer at distinct addresses. Write a Node-ID through the provisioning path, power-cycle, and confirm the node claims the written identifier and rejects a record whose CRC fails |

## 9. Open items

- `O-100` — `E0001-000100` is ordered and not received. Blocks every actuator module (ADR-0031 d10).
- `O-132` — The 3.3 V rail's current bound is not established: the buck's rating, the fitted inductor and the carrier's thermal design have not been read together, and no module specification states its own draw against it. Blocks `P5`.

## 10. Maturity

| Rung | State |
|---|---|
| Requirements-fixed | Reached for both revisions |
| **`E0001-000003` as-built** | **Current.** Fabricated, in service, its layout and fabrication outputs released |
| `E0001-000100` schematic-frozen | Not reached — schematic and layout released, `O-132` open |

`E0001-000100` reaches the next rung when `O-132` is closed.

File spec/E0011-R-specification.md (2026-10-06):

<!--
SPDX-FileCopyrightText: 2026 The IndustryGrow contributors
SPDX-License-Identifier: CC-BY-SA-4.0
-->

# A01-CLIMATE — module specification

- **Status:** Working specification, pre-schematic capture. `E0011-000001` laid out, not fabricated
- **Date:** 2026-10-05
- **E-number:** `E0011` · module class ID `0x80`
- **Governing ADRs:** ADR-0031 (rev 1), ADR-0032, ADR-0014 (rev 4), ADR-0015, ADR-0016, ADR-0017 (rev 2), ADR-0018, ADR-0003, ADR-0002 (rev 3)
- **Companions:** `E0001-R-specification.md`, `E0012-R-specification.md`, `E0002-R-specification.md`, `E0006-R-specification.md`, `E0008-R-specification.md`, `E0009-R-specification.md`
- **Supersedes:** `spec/A01-THERMAL-specification.md` (2026-09-07)

**This module runs on carrier `E0001-000100` only.** No earlier revision carries a transport for
an 8-bit class ID (ADR-0031 d10), and this module's Header B is a 2×10 that does not seat in the
2×8 socket those revisions fit (§5, `E0001-R-specification.md` §5.3).

Rationale for the decisions applied here is in the governing ADRs and is not restated.
Values marked `verify` are not confirmed against the manufacturer datasheet.

## 1. Scope

Requirements for the A01-CLIMATE actuator module in the indoor deployment variant: commanded
elements, actuator complement, drive, interfaces, power, thermal, interlock, mechanical and
firmware requirements, and their verification. The module acts on the grow-volume air and
carries every regulated variable of that medium — air temperature, humidity, and CO₂ when
populated (ADR-0031 rev 1 d2).

Not specified here:

| Subject | Owner |
|---|---|
| Carrier design and header allocation | `spec/E0001-R-specification.md` |
| Cultivation setpoints | `profiles/strawberry-day-neutral-v1.json` |
| Control-loop structure and gains | ADR-0015 d8/d18, `gateway/control_model.py` |
| Outdoor deployment variant | Not specified — `O-106` |
| Luminaire, its window, and the enclosure | A02-LIGHT and the enclosure design — `O-114` |
| Main-tract tempering unit — HX1, the `E1` pair, WB1, the `E2` fan and their sensing elements | `E0012-R-specification.md` |
| Rejection loop as a purchased assembly | ADR-0032, deferred |

## 2. Identification

| | Value |
|---|---|
| Module class | A01-CLIMATE |
| Module class ID | `0x80` — first actuator class (ADR-0031 d1, rev 1 d2; range per ADR-0014 rev 4 d6) |
| ID transport | Serial EEPROM, 24Cxx class, byte 0, I²C `0x50` (ADR-0014 d6). `E0001-000100` carries no module-ID strap |
| E-number | `E0011` — first assembly. A populate variant takes its own assembly E-number at design commit (ADR-0017 rev 2 d4) |
| Bare design | One layout, one class ID, one firmware image |
| Carrier | `E0001-000100`, `spec/E0001-R-specification.md`. Not fabricated — `O-100` |

### 2.1 Deployment variant — indoor

| | Indoor |
|---|---|
| Deployment envelope | Canopy ≤ 1 m², enclosed volume ≤ 3 m³, day cooling load ≤ 150 W (ADR-0032 d1) |
| Thermal boundary | A cabinet standing inside a building |
| Ambient | The room enclosing the cabinet, one step out (ADR-0014 d4) |
| Ambient air temperature | 15…30 °C (`E0009-R-specification.md`, indoor variant); 22 °C is the design value |
| Ambient relative humidity | 25…65 %RH (same) |
| Rejection sink | The same room air, through the liquid loop |
| Rejection load into the room | Per `T6`, bounded by `T8` |
| Field bus leaves the enclosure | No |
| Environmental qualification | Indoor, as M01–M05 |

### 2.2 Design basis

The loads the complement of §4 is sized against. These are inputs to this specification, not
requirements on it.

| Quantity | Value | Source |
|---|---|---|
| Grow-volume air | 0.43 m³ | enclosure, 516 × 516 × 1616 mm internal |
| Envelope area | 4.80 m² | same |
| Envelope conductance `U·A` | 2.95 W/K (12 mm OSB + 30 mm PIR) | computed; `O-105` for the identified value |
| Room temperature | 22 °C | §2.1 |
| Air setpoints | 20 °C day, 14 °C night | `profiles/strawberry-day-neutral-v1.json` |
| VPD band | 0.8–1.2 kPa, both photoperiods | same |
| Photoperiod | 16 h on, 8 h off | same |
| Luminaire | Outside the grow volume, radiating through a window; 19.2 W enters the volume | `O-114` |
| Transpiration | 140 ml/day, 5.8 g/h during the photoperiod | assumed; `O-111` |
| Main-tract load, day | 25 W | `U·A`·ΔT 5.9 W + luminaire 19.2 W + fans 3.9 W − humidity tract 4.1 W; the fan term follows the `E5` duty `O-128` settles |
| Main-tract load, night | 26 W | `U·A`·ΔT 23.6 W + fans 3.9 W − humidity tract 1.5 W |

With the luminaire inside the grow volume the day load is 38 W and `D10` is reached at the wet
edge of the VPD band; that case is outside this variant (`O-114`).

## 3. Function

A01 acts on the grow-volume air through two air tracts in parallel. Each element takes its own
demand and validity deadline (ADR-0031 d4); the node conditions and limits every demand on its
own state (`D9`, `D10`, `D11`) and executes it (ADR-0015 d18).

| Tract | Flow | Sets | Method |
|---|---|---|---|
| Main, assembly `E0012` | 56 m³/h | Air temperature | `E1` on HX1, floored above the grow-volume dew point (`D10`) |
| Humidity | 1.7 m³/h | Humidity ratio | `E3` subcools to a commanded coil temperature (`D11`), `E4` pumps reheat from WB2 at constant humidity ratio (`D12`, ADR-0032 d7) |

Gateway demands into a conditioned node; a main tract with a two-module thermoelectric stack on a finned exchanger rejecting into a water block, and a humidity tract with a subcooler, a thermal break with a condensate siphon, and a reheater that pumps its heat back out of the subcooler's rejection 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

### 3.1 Commanded elements

| ID | Element | Device | Command range | Expected operating range | Resolution |
|---|---|---|---|---|---|
| `E1` | Main thermoelectric stack | TEC1, TEC2 in `E0012`, series pair | −1.000 … +1.000, signed; positive heats the grow volume | −0.30 … 0 | 0.001 |
| `E2` | Main-tract fan | `SP0008` in `E0012`, integral to HX1 | 0.000 … 1.000 | 0.4 … 1.0 continuous, 1.0 in the `D15` pulse | 0.001 |
| `E3` | Subcooler thermoelectric module | 1 × 40 × 40 mm module | 0.000 … 1.000, unsigned; cooling only | 0 … 0.30 | 0.001 |
| `E4` | Reheater | Thermoelectric module bridging WB2 and HX3, cold face on WB2 | 0.000 … 1.000, unsigned; heating only | 0 … 0.35 | 0.001 |
| `E5` | Humidity-tract fan | `SP0008`, the same part as `E2` (`E0012-R-specification.md` §4) | 0.000 … 1.000 | 0.03 … 0.07 by fan law against the §3 tract flow, which is below any stable duty for `SP0008` (`O-128`); set at commissioning (`F7`) | 0.001 |
| `E6` | CO₂ metering valve | Solenoid, pulse-dosed, on J13 — **valve not fitted in the baseline** | 0.000 … 1.000 | — | 0.001 |

Full scale of `E1`, `E3` and `E4` corresponds to the string current limit of `D2`, not to the module's
`Imax`. The `E6` valve is not fitted under ADR-0003 d8 and §3.4; its drive is.

### 3.2 Published quantities

| Published quantity | Sensor | Sensor range | Expected operating range | Accuracy |
|---|---|---|---|---|
| WB1 block temperature | U1 DS18B20 in `E0012`, 1-Wire | −55…+125 °C | 22…30 °C, ceiling 45 °C (`D9`) | ±0.5 K over −10…+85 °C, ±2 K outside it |
| Main exchanger base temperature | U2 DS18B20 in `E0012`, same bus | −55…+125 °C | 9…17 °C; 15.8 °C day, 9.6 °C night | ±0.5 K over −10…+85 °C, ±2 K outside it |
| Subcooler coil base temperature | U3 DS18B20, same bus | −55…+125 °C | 5…12 °C; 7.6 °C day, 5.5 °C night, floor +1 °C (`D11`) | ±0.5 K over −10…+85 °C, ±2 K outside it |
| Reheater base temperature | U4 DS18B20, same bus | −55…+125 °C | 8…30 °C; 25.4 °C at the `D12` design point | ±0.5 K over −10…+85 °C, ±2 K outside it |
| Applied demand echo, per element | — (firmware state) | per §3.1 | per §3.1 | exact |
| Drive state, per element | — (firmware state) | `off` / `run` / `inhibited` / `derated` / `tripped` / `fault` | — | exact |
| Interlock state | `T2`–`T5` hardware lines | `armed` / `tripped` per line | `armed` | exact |

### 3.3 Exclusions

| Quantity | Owning module class |
|---|---|
| Grow-volume air temperature, humidity, VPD, CO₂ concentration | M01-CLIMATE |
| Air velocity at the canopy | M06-VENTILATION |
| Room temperature and humidity | M07-AMBIENT |
| Canopy PPFD and spectrum | M02-LIGHT |
| Cabinet `+12 V` bus current, door, leak | M05-SAFETY |
| Actuator energy consumption | DIN kWh meter over S0, read by M05 (ADR-0018 d5) |
| Condensate accumulation rate | M05-SAFETY, counted pulse input (ADR-0014 rev 7 d4) |
| Transpiration rate derived from condensate | Gateway soft sensor (ADR-0016 d20) |
| Luminaire drive | A02-LIGHT — not specified (ADR-0031 rev 1 d2) |

### 3.4 Partial populations

| Population | Fitted | Omitted |
|---|---|---|
| Baseline | `E1`–`E5` and their drivers, sensors and interlocks; the `E6` drive Q3, D5 and J13 | The `E6` valve, regulator and dosing (`O-110`) |
| CO₂ variant | All of `E1`–`E6`, the valve on J13 | — |

Both populations carry class ID `0x80` and one firmware image; `F2` and `F12` govern what an
unpopulated branch publishes and commands (ADR-0014 d1, d2).

## 4. Element and device complement

| Ref | Device | Function | Supply | Rail |
|---|---|---|---|---|
| U1–U4 | DS18B20, 1-Wire, 12-bit, 750 ms conversion, 3.0–5.5 V | Reported temperatures per §3.2. U1 and U2 are mounted in `E0012` | 3.3 V | 3V3 |
| RT1 | NTC 10 kΩ B25/85 3435, at WB1 in `E0012` | `T2` trip element; the comparator U7 is on this board | — | — |
| RT2 | NTC 10 kΩ, on a lead in the grow volume | `T3` trip element, both thresholds (ADR-0018 d10) | — | — |
| RT3, RT4 | NTC 10 kΩ B25/85 3435, on leads — **not fitted**; their dividers and filters are | Spare analog channels on `ADC_3` and `ADC_4` (§5.2) | — | — |
| TEC1, TEC2 | In `E0012`; parameters in `E0012-R-specification.md` §4 | `E1`, series pair | Series string | `+24 V` actuator |
| TEC3 | `SP0006`, the same part as TEC1 and TEC2 (`E0012-R-specification.md` §4) | `E3`, single | — | `+24 V` actuator |
| TEC4 | Module for `E4`, **not** `SP0006`; sized by `D16` and `T11`, and takes its own SP when specified (`O-103`) | `E4`, single | — | `+24 V` actuator |
| HX1 | In `E0012` | Grow-volume exchanger of the main tract, and the cabinet's circulation | — | — |
| HX2 | `SP0011`, 80 mm long. `h·A` ≥ 1.9 W/K at the §3 tract flow | Cold section of the humidity tract, carrying TEC3's cold face | — | — |
| HX3 | `SP0011`, 40 mm long. `h·A` ≥ 0.95 W/K at the §3 tract flow | Hot section of the humidity tract, carrying TEC4's hot face | — | — |
| WB1 | In `E0012` | Rejection side of `E1`, and its clamping plate | — | — |
| WB2 | Water block or cold plate, two working faces | Rejection side of `E3` and cold-side source for `E4` | — | — |
| U5 | TI DRV8262, HTSSOP-44, **single-H-bridge mode**. 4.5…60 V; 50 mΩ HS+LS; integrated charge pump for 100 % duty; integrated high-side current sense, IPROPI ±4 %; UVLO, CPUV, OCP, OTSD, `nFAULT` | `E1` direction and current regulation (`D2`, `D3`) | 3.3 V logic, `+24 V` power | `+24 V` |
| U6 | TI DRV8262, **dual-H-bridge mode**, 100 mΩ HS+LS per bridge | `E3` and `E4` current regulation, unidirectional (`D4`, `D11`, `D12`) | 3.3 V logic, `+24 V` power | `+24 V` |
| L1–L3 | Series inductor between the driver output and each string; values from `D4` (`verify`, `O-134`) | Output filter of the drivers' off-time current regulation, with C32–C34 (`D4`) | — | — |
| C32–C34 | 10 µF, 50 V, X7R, 1210, across each string at J4, J7, J8 (`verify`, `O-134`) | Output filter with L1–L3 (`D4`) | — | — |
| U7 | Dual comparator, open-drain, rail-to-rail input: `RT1` over-temperature and `SF1` coolant flow | Hardware interlocks `T2` and `T4` | 3.3 V | 3V3 |
| U8 | Quad comparator, open-drain, rail-to-rail input: the `RT2` window, the `FA1` airflow trip, and the `RT1` plausibility trip | Hardware interlocks `T3` (ADR-0018 d10), `T5` and the second half of `T2` | 3.3 V | 3V3 |
| U11 | Quad 2-input AND gate | Combines the `T2`–`T4` chain, the `T5` line and the firmware enable into each driver's sleep input (`T10`) | 3.3 V | 3V3 |
| Q4, D6 | Q4 Stanson ST2317S23RG, P-channel, SOT-23, `V_DS` −40 V, `V_GS` ±20 V, `R_DS(on)` ≤ 45 mΩ at −10 V and 25 °C, in the high side; D6 15 V Zener, gate-source clamp | Reverse-polarity block on the `+24 V` entry (`P8`) | — | `+24 V` actuator |
| Q3, D5 | Q3 Alpha & Omega AO3422, N-channel, SOT-23, `V_DS` 55 V, `R_DS(on)` ≤ 200 mΩ at `V_GS` 2.5 V, low side, gate from U9 channel 3 through R48 with R49 to ground; D5 onsemi MBR1H100SFT3G, Schottky, 100 V, 1 A, across J13. Valve coil current ≤ 1 A (`O-110`) | `E6` valve drive (`D14`) | — | `+24 V` actuator |
| U9 | NXP PCA9685PW, 16-channel 12-bit PWM generator, I²C Fm+, 2.3–5.5 V, 24–1526 Hz, address `0x40`, outputs LOW after power-on reset | Module-local drive expansion (ADR-0031 rev 1 d11) | 3.3 V | 3V3 |
| U10 | 24Cxx serial EEPROM, I²C `0x50` | Module class ID (ADR-0014 d6) | 3.3 V | 3V3 |
| SF1 | Coolant-flow switch, purchased (`T4`) | Rejection-loop interlock | — | — |
| FA1 | Alarm output of the `E5` fan; `SP0008` carries it only as a custom variant (`O-128`) | Humidity-tract airflow interlock (`T5`) | — | — |
| TB1 | Thermal-break insert between HX2 and HX3, with the low point and condensate outlet | `T9`, `M7` | — | — |

Deliberately absent:

| Not fitted | Reference |
|---|---|
| Digital trip element. `T2`–`T5` act without the MCU; U1–U4 report and derate, and trip nothing | ADR-0031 d7, `T10` |
| Current-sense shunt. U5 and U6 integrate high-side sense | `D2` |
| Interlock path through a driver input. `T2`–`T5` act on the driver enable | `T10` |
| Any device at `0x50`–`0x57` other than U10. The block is reserved project-wide for the ID EEPROM | ADR-0014 d6 |

## 5. Interfaces

Header positions claimed. The carrier side of every signal is `spec/E0001-R-specification.md`
§5, and this module requires `E0001-000100` (§2).

| Interface | Use |
|---|---|
| Header A pin 1 / 3 — 3V3, GND | Node logic supply (`P1`) |
| Header A pin 4 / 5 — `I2C_SCL`, `I2C_SDA` | U10 class ID at `0x50`, U9 drive expansion at `0x40`, and J14 (§5.2) |
| Header A pin 7 — `OW_DATA` | U1–U4 on one 1-Wire bus; 4.7 kΩ pull-up on the module |
| Header A pins 9, 10, 11, 13, 14 — `SPI_SCK`, `SPI_MISO`, `SPI_MOSI`, `SPI_CS1`, `SPI_CS2` | Claimed by no device; J14 (§5.2) |
| Header A pins 15, 16, 17, 18 — `GPIO_1`–`GPIO_4` | `T2`, `T3`, `T4`, `T5` interlock state, one line each (ADR-0031 d11) |
| Header A pin 20 — `PWM_1` | U5 EN — `E1` enable, held on while `E1` is driven (`D4`) |
| Header A pin 21 — `PWM_2` | U6 EN1 — `E3` enable, held on while `E3` is driven (`D4`) |
| Header A pin 22 — `PWM_3` | U5 VREF — `E1` current setpoint, RC-filtered to analog (`D2`, `D4`) |
| Header A pin 23 — `PWM_4` | U6 VREF1 — `E3` current setpoint, RC-filtered to analog (`D4`, `D11`) |
| Header B pin 1 / 2 — 3V3, GND | Node logic supply |
| Header B pin 3 — `GPIO_5` | U5 and U6 `nFAULT`, wired-OR, open-drain (ADR-0031 d11) |
| Header B pins 4, 5 — `GPIO_6`, `GPIO_7` | Spare inputs, 10 kΩ pull-down, J14 (§5.2) |
| Header B pin 10 / 12 — `ADC_1`, `ADC_2` | U5 IPROPI, U6 IPROPI1 — `E1` and `E3` string current |
| Header B pin 17 / 19 — `ADC_3`, `ADC_4` | RT3 and RT4 spare thermistor channels (§5.2) |

Every header signal the carrier offers is claimed. Only the two positions the carrier itself
leaves unassigned — Header B 7 and 14 — and the unfitted 5 V at Header A 2 stay unconnected
(`E0001-R-specification.md` `I4`, `I5`).

Module-local expansion on U9 (ADR-0031 rev 1 d11):

| U9 channel | Use |
|---|---|
| 0 | `E2` main-tract fan |
| 1 | U6 EN2 — `E4` enable, held on while `E4` is driven (`D4`) |
| 2 | `E5` humidity-tract fan, including the `D13` start pulse |
| 3 | `E6` CO₂ valve drive, Q3 gate |
| 4 | U5 PH — `E1` direction (`D3`) |
| 5, 6 | U5, U6 firmware enable, into U11 and never onto a driver's sleep input directly (`T10`) |
| 7 | U6 VREF2 — `E4` current setpoint, RC-filtered to analog (`D4`, `D12`) |
| 8–15 | `AUX_1`–`AUX_8`, signal reserve on J14 (§5.2) |

### 5.1 Connectors

| Ref | Connector | Carries |
|---|---|---|
| J1, J2 | 2×12 and 2×10, 2.54 mm | Carrier headers A and B (ADR-0014 d5, `E0001-000100`) |
| J3 | Screw terminal, 2-pole, 5.00 mm | `+24 V` actuator section entry, `SP0010` |
| J4, J7, J8 | Screw terminal, 2-pole, 5.00 mm | `E1`, `E3`, `E4` element outputs |
| J5, J9 | Micro-Fit 3.0, 1×4, horizontal | `E2` and `E5` fans: supply, return, duty, alarm |
| J6 | Micro-Fit 3.0, 1×5, horizontal | `E0012` sensing: 1-Wire for U1 and U2, `RT1` |
| J10 | Micro-Fit 3.0, 1×3, horizontal | Humidity-tract 1-Wire for U3 and U4 |
| J11, J12 | Micro-Fit 3.0, 1×2, horizontal | `RT2` lead, `SF1` flow switch |
| J13 | Screw terminal, 2-pole, 5.00 mm | `E6` CO₂ valve |
| J14 | 2×14, 2.54 mm | Signal reserve (§5.2) |
| J15 | Micro-Fit 3.0, 1×4, horizontal | `RT3` and `RT4` leads (§5.2) |

### 5.2 Signal reserve

Reserve fitted in both populations of §3.4. No reserve line is claimed by a requirement of this
specification, and none carries a published quantity.

| Reserve | Count | Source | Reaches |
|---|---|---|---|
| Drive channels `AUX_1`–`AUX_8` | 8 | U9 channels 8–15, totem pole, ≥ 12 mA sink at 0.5 V, 10 mA source at ≥ 2.3 V, 400 mA per package | J14 |
| `I2C1` segment | 1 | Header I²C; addresses outside `0x40` and `0x50`–`0x57` are free | J14 |
| `SPI2` segment with both chip selects | 1 | Header SPI, claimed by no device on this module | J14 |
| Carrier inputs | 2 | `GPIO_6`, `GPIO_7`, 10 kΩ pull-down to ground | J14 |
| Analog channels | 2 | `ADC_3`, `ADC_4` from the RT3 and RT4 dividers | J14 and Header B |
| Header positions left unassigned | 2 | Header B positions 7 and 14, `RESERVED` on the carrier and unconnected here | — |
| Thermistor leads | 2 | `RT3`, `RT4`, conditioning fitted, thermistors not fitted | J15 |
| 1-Wire addresses | Bus-limited, not pin-limited | The `OW_DATA` bus of §4 | J6, J10 |
| Spare AND gate | 1 | U11 section D, inputs tied to ground, output unconnected | — |

## 6. Drive requirements

| ID | Requirement | Reference |
|---|---|---|
| `D1` | `E1` is two modules wired as one series string. At the design points the string carries 1.45 A at 9.5 V (day, ΔT 12 K, `Qc` 25 W) and 1.68 A at 11.2 V (night, ΔT 15 K, `Qc` 26 W), all `verify` | `O-103` |
| `D2` | `E1` drive is closed-loop **current**, regulated by U5 against its `VREF` setpoint. String current limit 1.98 A, realized by the IPROPI resistor at full-scale `VREF`, against a 10 A RMS single-H-bridge rating; `D1` decides whether it is enough. The integrated sense serves this loop only; no energy or consumption quantity is published from it | ADR-0018 d5 |
| `D3` | `E1` direction reversal is by the U5 PH input. Reversal is permitted only after the drive has been at zero for `D5` | ADR-0031 d5 |
| `D4` | Every string runs in its driver's off-time current regulation: the enable is held on while the element is driven and the current is set on `VREF` — U5 `VREF` for `E1`, U6 `VREF1` for `E3`, U6 `VREF2` for `E4`. Off-time is one of 7 / 16 / 24 / 32 µs, set per driver by its `TOFF` pin, so `E3` and `E4` share U6's. Minimum on-time is the 1.5 µs blanking time. Each string carries L1–L3 in series and C32–C34 across it; string current ripple at the connector is ≤ 5 % of setpoint at every operating point of `D1`, `D11` and `D16` (`verify`) | ADR-0031 d11, `O-103`, `O-134` |
| `D5` | Dead band \|demand\| < 0.05 commands zero drive; minimum dwell at zero before a sign change is 60 s (commissioning value, `F7`) | ADR-0031 d5 |
| `D6` | Every element of §3.1 is commanded independently; no element's demand forces another's | ADR-0031 d4 |
| `D7` | Demand slew is limited to 0.05 s⁻¹ on `E1` and `E3` (commissioning value, `F7`) | ADR-0015 d18 |
| `D8` | A demand whose validity deadline has expired drives its element to the safe output: `E1`, `E3`, `E4`, `E6` to zero; `E2` and `E5` to full | ADR-0031 rev 1 d6 |
| `D9` | Water-block temperature from U1 derates every thermoelectric demand: full scale below 35 °C, linear to zero at **45 °C**, re-enable below 32 °C (`verify`). Runs on the node and applies to any commanded value | ADR-0031 d4 |
| `D10` | Main exchanger base temperature from U2 is floored so the surface stays above the grow-volume dew point. The operative floor arrives with the demand — 13.4 °C day, 3.7 °C night at the wet edge of the band, computed from the §2.2 setpoints and VPD band. The node holds a commissioned absolute minimum of 3.0 °C (commissioning value, `F7`) that no command lowers. `E1` cooling demand is derated to hold whichever floor is higher | ADR-0032 d5, ADR-0015 d18, §10.1 |
| `D11` | `E3` is unidirectional. Its demand is conditioned against a coil-temperature setpoint measured at U3, with a hard floor of **+1 °C** (commissioning value, `F7`) below which cooling demand is driven to zero | ADR-0032 d4, ADR-0003 d7 |
| `D12` | `E4` is the last element of the humidity tract, downstream of HX2, and pumps from WB2 rather than dissipating. `E4` is inhibited whenever `T5` is tripped or `E5` demand is below `D13`'s minimum | `T5`, ADR-0032 d7 |
| `D13` | `E5` starts with a full-scale pulse before settling to its commanded duty, and commanded duty below the fan's stable minimum is driven as zero. Pulse duration and that minimum are `SP0008`'s and are unset; the superseded part's 250 ms and 0.15 do not carry over | `E5`, `O-128` |
| `D14` | `E6` is commanded as a pulse train against a commissioned minimum open time; it is inhibited whenever `E5` demand is zero. Verified at the CO₂ population only | `O-110` |
| `D15` | `E2` also carries the pollination pulse: a full-scale excursion over the flowering zone at the profile's duration and interval, issued by the gateway as an ordinary demand. No pulse timing is node-local | ADR-0003 d13, ADR-0031 rev 1 d2 |
| `D16` | `E4` is unidirectional. At the design point it delivers 6.6 W to HX3 at 0.51 A and 1.61 V, drawing **0.82 W**; at the largest lift, WB2 at 22 °C against a 30 °C HX3, it draws **1.69 W** (both `verify`, computed on the TEC1–TEC3 parameters pending `O-103`). Demand is conditioned against U4 | ADR-0032 d7, `O-103` |

## 7. Power

| ID | Requirement | Reference |
|---|---|---|
| `P1` | Node logic is powered from the `+12 V` SELV sensor bus and derives 3.3 V on the carrier. No actuator element is on that rail | ADR-0018 d3 |
| `P2` | Elements are fed from the `+24 V` actuator section, `SP0010`: TDK-Lambda Vega 650 (`K60050B`), C5 module, 21.6–31 V at 10 A in one slot. Chassis total 650 W is shared across fitted modules and derates 2.5 % per °C above 50 °C. Output to output and output to earth are isolated to 200 V dc operational, which is what `P5` rests on | ADR-0018 d3, `O-104` |
| `P3` | Draw at the worst simultaneous point: `E1` 18.7 W, `E3` 9.5 W, `E4` 1.7 W, `E2` 2.9 W, `E5` 2.9 W — 35.7 W, 1.5 A from `+24 V` (`verify`). `E2` and `E5` are the same part, so each is bounded at its full-duty draw. One C5 module carries the module with the balance available to other branches | `D1`, `SP0008` |
| `P4` | Per-branch overcurrent protection is the supply module's own current limit plus the drivers' OCP; no central per-load fuse | ADR-0018 d8 |
| `P5` | The switched return is not shared with the logic or analog ground at the module. Isolation of the command path lives at this actuator | ADR-0018 d7, d8 |
| `P6` | Conduction loss at the current limits is 0.20 W on U5 (50 mΩ HS+LS, single H-bridge) and 0.50 W on U6 (100 mΩ per bridge, dual H-bridge, `E3` and `E4` together). Junction-to-ambient of the DDW package is 22.2 K/W, and each thermal pad is bonded to a copper pour sized against it | U5, U6 |
| `P7` | Module energy at the design profile is 0.73 kWh/day: `E1` 0.37, `E3` 0.15, `E4` 0.01, `E2` 0.07, `E5` 0.01, rejection-loop pump 0.12 (`verify`). The `E5` term follows the duty `O-128` settles. Divergence from the M05 S0 meter beyond 15 % invalidates the §2.2 basis | ADR-0018 d5 |
| `P8` | The `+24 V` entry carries a reverse-polarity block: a P-channel MOSFET in the high side with its gate clamped against the rail, ahead of the transient suppressor and every load. Conduction loss at the `P3` draw is ≤ 0.15 W (`verify`). The return is not switched, so the `P5` bond stays a single point | `P3`, `P5` |

## 8. Thermal requirements and interlocks

![Four trip elements each reach a comparator section without the MCU in the path; three of them pull one wired-AND enable chain while the tract-airflow trip reaches only the gate that enables the humidity-tract driver, so a loss of that airflow removes drive from the subcooler and reheater while the main stack keeps running; a quad AND gate combines the chain, that fourth trip and a firmware enable into each driver's sleep input, so firmware can withhold an enable and assert none; each trip line is read back on its own header input and the wired-OR driver fault returns on another](./figures/a01-climate-enable-chain.svg)

| ID | Requirement | Reference |
|---|---|---|
| `T1` | The main tract's heat-removal duty is specified by `E0012` (`T1`) | `E0012-R-specification.md` |
| `T2` | **Rejection plausibility window** (self-protective), independent of the MCU, gateway and cloud: `RT1` → U7 and U8 → driver enable on U5 and U6, both halves on one reported line. High trip 60 °C with 2.7 K hysteresis, 15 K above the `D9` ceiling. Low trip 0 °C with 4.1 K hysteresis, which is also what an open `RT1` lead reads; a shorted lead reads past the high trip | ADR-0031 d7 |
| `T3` | **Grow-volume temperature window trip** (process-protective), independent of the MCU, gateway and cloud: `RT2` → U8 → driver enable on U5 and U6. High trip 35 °C with 2.6 K hysteresis, low trip 5 °C with 3.4 K. An open or shorted `RT2` lead reads outside the window and trips | ADR-0018 d10, ADR-0031 d7 |
| `T4` | **Coolant-flow interlock** (self-protective): loss of flow in the rejection loop removes driver enable on U5 and U6 in hardware | ADR-0031 d7 |
| `T5` | **Humidity-tract airflow interlock** (self-protective): loss of the `FA1` alarm output removes drive from **both** `E3` and `E4` in hardware | ADR-0031 d7 |
| `T6` | The rejection loop dissipates ≥ 65 W continuous with supply water at ≤ 25 °C in a 22 °C room (`verify`) | ADR-0032 d3, `P3`, `T1` |
| `T7` | Condensate forms only on HX2, is collected at the `TB1` low point through a liquid seal, and is drained clear of the grow volume. HX1 forms none under `D10` (`E0012` `T2`) | ADR-0032 d5, `O-107` |
| `T8` | The room absorbs the `T6` rejection load with an ambient rise ≤ 2 K (`verify`). Ambient outside 15…30 °C is outside this variant | §2.1 |
| `T9` | Conduction between HX2 and HX3 through `TB1` is ≤ 1 W at a section-to-section ΔT of 18 K (`verify`) | `M7` |
| `T10` | `T2`–`T5` act on the driver enables directly. Firmware reads their state but cannot override or re-arm any of them | ADR-0015 d11, ADR-0018 d10 |
| `T11` | **Zero drive on `E4` is not zero heat transfer.** TEC4 conducts WB2's heat into HX3 whenever WB2 is the warmer plate, including at the `D8` safe output and at every interlock trip. TEC4 is sized so that this uncommanded reheat stays ≤ **3 W** (`verify`) at the largest reverse lift, WB2 at the `D9` ceiling against a 25.4 °C HX3. The TEC1–TEC3 part fails that bound at 0.864 W/K and is therefore not TEC4 | ADR-0032 d7, ADR-0031 d6, `D8`, `O-103` |
| `T12` | The cold section presents ≥ 1.78 W/K and the reheat section ≥ 0.63 W/K to the air at the §3 tract flow, both at the day design point: 20 °C inlet at the wet edge of the band, 7.6 °C coil, 5.8 g/h of condensate. `O-128` sets the flow, and the requirement rises with it | `D11`, `D12`, `O-111` |

## 9. Mechanical requirements

![Vertical section through the cabinet: both tracts sit outside the grow volume and reach it through four sealed, thermally broken penetrations; the main tract draws from a floor intake, passes HX1 with its fan E2 in an outer shaft and returns through a horizontal ceiling slot aimed at the far wall, so the air crosses the ceiling, falls down the far wall and returns along the floor; the humidity tract draws high on the opposite wall, passes E5, the condensing exchanger HX2 with E3, the thermal break TB1 carrying the low point and liquid seal, and the reheat exchanger HX3 with E4, returning low; condensate leaves TB1 by a drain clear of the volume, the luminaire radiates through a ceiling window, and RT2 reaches the volume on a lead through the floor](./figures/a01-climate-air-path.svg)

| ID | Requirement | Reference |
|---|---|---|
| `M1` | TEC3 and TEC4 are each clamped between their exchanger and their plate at the datasheet clamping force, through a metal plate with disc springs. No printed part carries clamping load. The `E1` pair is clamped by `E0012` (`M1`) | `O-103` |
| `M2` | Both faces of TEC3 and TEC4 carry a thermal interface material rated for continuous 100 °C (`verify`) | `O-103` |
| `M3` | Each tract penetrates the cabinet wall; every penetration is sealed and thermally broken, and no metal is carried through the insulation | `O-107` |
| `M4` | The main tract's intake and discharge terminations are specified by `E0012` (`M5`) | `E0012-R-specification.md` |
| `M5` | `RT2` reaches the grow volume on a lead; no I²C crosses that lead | ADR-0014 d3, ADR-0018 d10 |
| `M6` | Printed parts are PETG. No printed part is in direct thermal contact with a module hot face, a water block or HX3, and no printed surface exceeds **60 °C** continuous (`verify` — PETG HDT ≈ 70 °C at 0.45 MPa) | `O-107` |
| `M7` | `TB1` is a printed insert of 15–20 mm with thin walls and an internal air passage, carrying the tract's low point and its liquid seal | `T9`, `T7` |
| `M8` | HX2 and HX3 are degreased before assembly; HX1 is `E0012`'s (`M3`) | `T7` |
| `M9` | The humidity tract's duct carries the same bore and the same flange as the main tract's (`E0012`'s §5), so sections, collars, flanges and terminations interchange between the tracts. A flow restriction `O-128` may call for is an element in the tract, not a reduction of the bore | ADR-0032 d8, `O-128` |
| `M10` | HX2 and HX3 sit in duct sections sealed around the profile, so no air bypasses the fins. HX2 is mounted fins upward, its base at the bottom of the tract and falling toward the `TB1` low point | `T7`, `M7`, `M9` |
| `M11` | Every field lead is retained at the board against withdrawal: a screw clamp at J3, J4, J7, J8 and J13, a positive latch at J5, J6, J9, J10, J11, J12 and J15 (§5.1) | `T2`–`T5` |
| `M12` | The board is 147 × 110 mm on four copper layers: `F.Cu` and `B.Cu` carry signals, `In1.Cu` is a full `GNDPWR` plane, `In2.Cu` a full `GND` plane | ADR-0002 d12 |

The tract's designed parts — `TB1`, the exchanger sections of `M10`, the wall penetrations of `M3` and the condensate collector of `O-109` — are development sources in `project/mechanical/`, carrying no identifier while the design iterates (ADR-0032 d8).

## 10. Firmware requirements

| ID | Requirement | Reference |
|---|---|---|
| `F1` | Read the class ID from EEPROM `0x50` byte 0 at boot. `0x00` and `0xFF` are *unidentified*, never a class | ADR-0014 d6 |
| `F2` | Enumerate the 1-Wire bus at boot and publish only the quantities in §3.2 whose devices respond | ADR-0014 d2 |
| `F3` | The inner loop runs on the node at the element's rate; the gateway issues each demand and its validity deadline only | ADR-0015 d18 |
| `F4` | Enforce `D2`, `D5`, `D7`–`D14` in node firmware, independently of the commanded value | ADR-0015 d18 |
| `F5` | Publish the state of `T2`–`T5`. A trip is reported and latched in telemetry until the node is reset | `T10` |
| `F6` | Publish no energy or consumption quantity | ADR-0018 d5 |
| `F7` | Deployment constants — current limits, dead band, dwell, slew, the `D10` floor, the `D11` coil floor, fan mapping — are node-local and set at commissioning, not carried in the profile | ADR-0015 d18, ADR-0028 |
| `F8` | Loss of U1 for more than 5 s (`verify`) is treated as the `D9` ceiling reached; loss of U2 or U3 drives `E1` or `E3` respectively to zero | `D9`, `D10`, `D11` |
| `F9` | A `nFAULT` assertion drives both strings to zero, is published as drive state `fault`, and is latched until the node is reset | U5, U6 |
| `F10` | The humidity setpoint the node accepts is a **coil temperature** for U3, not a humidity or VPD value. No M01 quantity is an input to this node | ADR-0032 d4, ADR-0031 d8, `D11` |
| `F11` | Loss of the U9 I²C link drives every U9-borne element to its `D8` safe output. `E2` and `E5` are wired so that a de-asserted U9 output runs them at full without firmware acting | ADR-0031 rev 1 d6, d11, `O-113`, `O-135` |
| `F12` | An unpopulated branch publishes no demand echo and accepts no demand for its elements | §3.4, ADR-0014 d2 |

### 10.1 Subjects

Baked defaults in the unregulated range. ADR-0005 d7 makes these `uavcan.pub.<name>.id` and
`uavcan.sub.<name>.id` register entries.

| ID | Direction | Quantity | Type |
|----|---|---|---|
| 4352–4355 | publish | U1–U4 temperature, §3.2 | `uavcan.si.sample.temperature.Scalar` |
| 4356–4361 | publish | Applied demand and drive state, `E1`–`E6` | `industryflow.greenhouse.actuator.ElementState` |
| 4362 | publish | `T2`–`T5` line state, now and latched (`F5`) | `industryflow.greenhouse.actuator.InterlockState` |
| 4368–4373 | subscribe | Demand and validity horizon, `E1`–`E6` | `industryflow.greenhouse.actuator.Demand` |

| `Demand` field | `E1` | `E2`, `E5` | `E3` | `E4`, `E6` |
|---|---|---|---|---|
| `value` | −1 … +1 | 0 … 1 | 0 … 1 | 0 … 1 |
| `kelvin` | `D10` floor; NaN = commissioned minimum only | NaN | `D11` coil setpoint; NaN = no demand executed | NaN |
| `horizon_ms` | validity from reception; 0 = `D8` safe output | same | same | same |

## 11. Verification

| ID | Verifies | Method |
|---|---|---|
| `V1` | `D1`, `P3` | Measure `E1` string current and voltage at 24 V against a water block held at 25 °C; record the ΔT–current curve to `i` = 0.30 |
| `V2` | `D2`, `D4` | Measure each string's current and ripple at its connector, at 25 %, 50 % and 100 % of its limit, with a current probe; cross-check against IPROPI |
| `V3` | `D3`, `D5` | Command an `E1` sign reversal; confirm zero drive is held for the dwell and that no reversal occurs inside it |
| `V4` | `D7`, `D8`, `F4` | Step each element to full scale and confirm slew. Stop publishing each demand; confirm `E1`, `E3`, `E4` reach zero and `E2`, `E5` reach full within the deadline |
| `V5` | `T1`, `T6` | Executed on `E0012` (`V1`), whose pull-down run also records the loop supply temperature and the main tract's heat-removal duty |
| `V6` | `T2` | Heat `RT1` past the high trip with the MCU held in reset; confirm both driver enables are removed. Repeat with `RT1` open-circuit and with it shorted, and confirm the enables are removed in each case |
| `V7` | `T3` | Drive `RT2` past each threshold in turn with the MCU held in reset; confirm both driver enables are removed at each |
| `V8` | `T4` | Stop coolant flow with `E1` at the limit; confirm both driver enables are removed |
| `V9` | `T5` | Stall the `E5` fan with `E3` and `E4` running; confirm both lose drive in hardware |
| `V10` | `T10` | Attempt to re-arm each trip from firmware; confirm it cannot |
| `V11` | `D9`, `F8` | Raise the water block past 35 °C with `E1` at full scale; record the derate curve and the 45 °C clamp. Disconnect U1; confirm the clamp |
| `V12` | `D10` | Command a floor below 3.0 °C; confirm the node holds 3.0 °C. The wet-edge run that confirms no free water on HX1 is `E0012`'s (`V3`) |
| `V13` | `D11`, `T7` | Command a coil setpoint below +1 °C; confirm cooling demand is driven to zero at the floor, that HX2 does not frost over 8 h, and that free water forms on HX2 and nowhere else in the tract |
| `V14` | `D12`, `T9`, `T12` | Run the humidity tract at its design point; measure the humidity ratio and temperature at tract inlet and outlet, and the HX2-to-HX3 conduction by substituting a known electrical load for `E3`. Derive each section's conductance from its inlet, outlet and base temperatures |
| `V15` | `D13` | Command `E5` from zero to 0.17; confirm the start pulse and that the rotor starts on ten of ten attempts |
| `V16` | `D6`, `D15` | Command every element independently at three levels; confirm no element's demand moves another. Command the pollination pulse; confirm `E2` reaches full for the commanded duration and returns to its prior demand |
| `V17` | `F9` | Force a driver fault at reduced `VREF`; confirm zero drive on both strings, the published state, and the latch |
| `V18` | `F11` | Open the U9 I²C link with all elements running; confirm `E1`, `E3`, `E4` reach zero and `E2`, `E5` run full |
| `V19` | `D14`, `F1`, `F6`, `F12` | Read the published class ID; confirm `0x80`. Enumerate every published subject; confirm no energy or consumption quantity is among them, and that the unpopulated CO₂ branch publishes and accepts nothing. `D14`'s dosing is executed at the CO₂ population only |
| `V20` | `P6` | Measure U5 and U6 case temperatures at their limits for 1 h |
| `V21` | `P7` | Log the M05 S0 meter over a full 24 h profile; compare against the `P7` figure |
| `V22` | `M6` | Thermograph the humidity tract's printed parts at the `T6` rejection load; confirm no surface exceeds 60 °C |
| `V23` | `M4`, `M9` | Executed on `E0012` (`V7`, `V11`) |
| `V24` | `T8` | Run at the `T6` rejection load for 4 h in the installed room; record the ambient rise |
| `V25` | `P1`, `P5` | Measure isolation between the switched return and both logic and analog ground; confirm no element current returns on the `+12 V` bus |
| `V26` | `M1`, `M2`, `M8` | Record clamping force on TEC3 and TEC4 against the module datasheet, the TIM temperature rating, and that HX2 and HX3 were degreased |
| `V27` | `M3`, `M5`, `M7`, `M10` | Inspect every penetration for seal and thermal break, confirm no metal crosses the insulation, confirm no I²C runs on the `RT2` lead, and confirm `TB1` drains at its low point. Confirm the exchanger sections seal around the profile and that HX2's base falls toward `TB1` |
| `V28` | `F2`, `F10`, `F12` | Remove one 1-Wire device; confirm its quantity is not published. Offer the node a humidity, VPD or CO₂ setpoint; confirm it is refused |
| `V29` | `F3`, `F5`, `F7` | Record the node loop rate; confirm a trip is published and latched until reset; confirm every `F7` constant is read from node-local storage and none from the profile |
| `V30` | `P2`, `P4`, `P8` | Short one element at its connector with the string at its limit; confirm the supply module's current limit and the driver OCP act, that no other branch on the C5 module drops out, and that the supply recovers on removal. Apply the `+24 V` entry reversed at the supply's current limit for 60 s; confirm no current reaches the rail and that the module runs unchanged afterwards |
| `V31` | `D16`, `T11`, ADR-0032 d7 | Reheat delivered to HX3 measured against `E4`'s electrical input at the design point and at the largest lift; the coefficient of performance shall exceed 1 at both. With `E4` at zero drive and WB2 held at the `D9` ceiling, the heat crossing into HX3 measured against `T11`'s 3 W bound |
| `V32` | `M11` | Pull each field lead along its axis at the connector's rated retention force (`verify`) and hold 10 s; confirm no connector separates and no conductor leaves its clamp |
| `V33` | `M12` | Inspect `E0011-000001-D-fab.zip`: four copper layers, `In1_Cu` a `GNDPWR` plane, `In2_Cu` a `GND` plane. Confirm the ordered stackup names four layers |

## 12. Open items

- `O-100` — `E0001-000100` is laid out and not fabricated; owned by `spec/E0001-R-specification.md`, consumed here. A01 cannot run on `E0001-000003`: actuator class IDs need the EEPROM transport (ADR-0031 d10). Blocks fabrication of this module.
- ~~`O-101`~~ — ~~No actuator-taxonomy ADR (ADR-0014 d9).~~ — closed 2026-09-07 by ADR-0031.
- ~~`O-102`~~ — ~~No DSDL type for a signed or unsigned actuator demand with a validity deadline.~~ — closed 2026-10-05 by `industryflow.greenhouse.actuator.Demand.1.0`, §10.1.
- `O-103` — Thermoelectric module not selected; α, R, K, clamping force and TIM are unconfirmed, and L1–L3 and C32–C34 follow from them. Driver continuous RMS current by package is unread. TEC4 is a separate selection under this item and is not the TEC1–TEC3 part: bounded below by `D16`'s largest lift, above by `T11`'s conductance ceiling. Blocks `D1`, `D4`, `D16`, `M1`, `M2`, `T11`.
- `O-104` — Vega 650 startup behaviour, the ramp and the sequence of one output against another, is unconfirmed against the manual, and the per-module inhibit or enable option is an ordering suffix that has not been chosen. Output isolation is confirmed at 200 V dc operational and no longer part of this item. Blocks `P2`.
- `O-105` — Envelope conductance is computed, not identified (ADR-0016 survey). Blocks sufficiency of `T1` and the `D10` floor.
- `O-106` — Outdoor deployment variant not specified.
- `O-107` — Wall penetrations, thermal breaks and the condensate drain are mechanical design. Blocks `M3`, `M6`, `T7`.
- `O-108` — The dry edge of the night VPD band is not reachable: 1.2 kPa at 14 °C requires a coil at −6 °C, and `D11`'s floor yields 0.94 kPa. Resolved by the profile — narrow the night band, add a defrost cycle, or raise the night setpoint — not by this module.
- `O-109` — The condensate collector, its count transducer and its lead are mechanical design of this module's humidity tract; the counter itself is M05's (ADR-0014 rev 7 d4) and `E0006-000001` has no free pulse input (`O-116`). Volume per count is a commissioning constant of the collector and is unset. Blocks the `O-111` measurement.
- `O-110` — CO₂ branch unspecified: source, regulator, valve, minimum dose against the §2.2 grow volume, and CO₂ accumulation in an occupied room. Blocks `D14` and the §3.4 CO₂ population.
- `O-111` — Transpiration is assumed at 140 ml/day and is unmeasured; it sets the humidity-tract mass flow. Closed by the first `O-109` measurement.
- `O-127` — The main tract's 56 m³/h is the fan's free-air figure, not its operating point; owned by `E0012-R-specification.md`, consumed here. Blocks the air-side terms of §2.2 and the flow in §3.
- `O-128` — `E5` mounts `SP0008`, the same fan as `E2`, and the tract flow cannot be reached by duty alone. `SP0008` delivers 56 m³/h free air against the superseded part's 10.1 m³/h, so holding the §3 tract flow puts the duty near 0.05, an order below where a ball-bearing DC fan turns stably. One of three closes it: a fixed restriction sized so the fan's minimum stable duty yields the §3 flow, intermittent operation at that minimum, or a smaller fan for this tract. The variant question is the same item: `SP0008` carries a duty input and an alarm output only as custom variants, and `T5`'s trip element is that alarm, which the superseded part had as standard. Blocks `T5`, `D13`, `P3`, `P7`'s `E5` term and the `§3.1` range.
- `O-129` — Humidity tract as a parallel branch off the main tract instead of a tract with its own fan: fed by `E2`, flow set by branch diameter and take-off geometry, humidity still set by `E3`'s current. Deferred to a later iteration; this build brings each regulated variable under control on its own tract first. Closing it needs the branch diameter, the take-off angle, the split at `E2`'s lowest continuous duty, `T5`'s element moved to `E2`, and `D16` and `T11` recomputed at the branch flow. Closes `O-128` if adopted, and amends ADR-0031 d4's element list and ADR-0032 d4.
- ~~`O-113`~~ — ~~U9 part not selected.~~ — closed 2026-09-11 by the PCA9685PW of §4: outputs are LOW after power-on reset, which is the state `F11` wires each element's safe output to.
- ~~`O-131`~~ — ~~HX2 and HX3 named as Fischer LAM 5 catalogue aggregates, rated with their own fan at a flow the tract does not carry.~~ — closed 2026-09-11: both are one extruded profile cut to two lengths, specified in §4 against the §3 tract flow and mounted by `M10`.
- `O-114` — The luminaire's position relative to the grow volume sets 19 W or 32 W of §2.2 day load and decides whether `D10` binds at the wet edge of the band. Owned by A02-LIGHT and the enclosure, consumed here.
- ~~`O-115`~~ — ~~No governing ADR for cabinet climate conditioning.~~ — closed 2026-09-08 by ADR-0032.
- `O-134` — U6 has one `TOFF` pin for `E3` and `E4`. `E4` near 1.6 V needs about 7 % duty from `+24 V`, which the 1.5 µs minimum on-time reaches only at the longer off-times, and the longer off-time raises `E3`'s ripple in L2. The U6 off-time, L2, L3 and C33–C34 are set together, after `O-103`. Blocks `D4`.
- `O-135` — U9 `OE` is tied to GND, so a U9 that keeps its supply while its I²C link is lost holds its last outputs: `FW_EN_U6`, `E4` enable and `VREF2`, and the `E2` and `E5` duties. `E1` and `E3` stop from the header lines; `E4`, `E2` and `E5` do not reach their `D8` safe output. Blocks `F11`.

## 13. Maturity

| Rung | State |
|---|---|
| **Pre-schematic** | **Current.** Complement and requirements fixed; values estimated or `verify` |
| Schematic-frozen | Not reached |
| As-built | Not reached |

Next rung requires: `O-103`, `O-104` and `O-135` closed, and the component values that
follow — L1–L3, C32–C34 and the driver off-times — computed against the selected thermoelectric
modules. Both `VREF` dividers and the `U7` and `U8` thresholds are computed.

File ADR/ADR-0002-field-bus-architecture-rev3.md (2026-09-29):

<!--
SPDX-FileCopyrightText: 2026 The IndustryGrow contributors
SPDX-License-Identifier: CC-BY-SA-4.0
-->

# ADR-0002 (rev 3): Field bus architecture — Cyphal/CAN over WeAct STM32F4 core board on custom carrier PCB with stateless-edge Raspberry Pi gateway

- **ID:** ADR-0002 (rev 3)
- **Status:** Accepted
- **Date:** 2026-05-16
- **Project:** IndustryGrow
- **Parent:** ADR-0001
- **Supersedes:** ADR-0002 (rev 2, same date)

## Revision history

- **rev 3 (2026-05-16)** — Gateway side only: the rev-2 persistent SQLite local buffer becomes an in-memory ring buffer and the gateway hardware minimum drops to Raspberry Pi 3B+, following ADR-0004 rev 1's stateless-edge reframing. The smart-node side (carrier, WeAct core board, ATECC608, sensor-module header) is unchanged from rev 2. See decision 6, decision 8, and alternative J. Earlier revisions: rev 1 placed the MCU directly on the carrier (alternative D); rev 2 specified a Pi 5 with a persistent SQLite buffer (alternative J).
- **Amendments** — decision 10 (2026-08-15): WeAct publishes no gerbers and no licence; corrects the premises of decisions 2 and 4.
- **Amendments** — decision 11 (2026-08-25): the gateway is the bus time-synchronization master; fixes the network time base that decision 1 leaves unassigned.
- **Amendments** — decision 12 (2026-09-29): the copper-layer count of a board is set by its specification; qualifies the layer estimate in decision 3.

## Context and problem

ADR-0001 committed IndustryGrow to an open-core model serving deployments from apartment cabinets to commercial facilities. This ADR decides *how* the field-level instrumentation works: which bus, which protocol, which hardware, which gateway, and where the security boundary sits.

A cabinet contains ~15–20 sensors and actuators across functional subsystems (climate, lighting, irrigation, plant monitoring, pollination, power/safety). They are heterogeneous at the silicon level — I²C, SPI, analog, PWM, GPIO — but must present a uniform interface to the platform. **Every deployment — community self-build, hobbyist, commercial managed — uses the same MCU, same firmware, same protocol, same carrier PCB.** Uniformity is a load-bearing project value.

This revision changes only the gateway side. Rev 2 specified Raspberry Pi 5 + Waveshare 2-CH CAN HAT and "local buffering via SQLite for resilience against transient network loss". A subsequent review (captured in ADR-0004 rev 1) reframed the gateway as a **stateless edge** — persistent local state is minimized to identity and configuration, runtime state lives in RAM, audit-trail moves to the IndustryFlow platform side. This has two practical consequences for ADR-0002:

1. **Local SQLite buffer becomes an in-memory ring buffer.** Persistent crash-safe local storage is no longer required.
2. **Gateway hardware minimum drops.** Without a write-heavy local audit log, a Raspberry Pi 3B+ with 1 GB RAM is sufficient for apartment-scale deployments. Pi 4 and Pi 5 remain valid choices for higher-traffic or commercial deployments where extra headroom matters.

The smart-node side (carrier PCB, WeAct core board, F405/F412/F446 drop-in, ATECC608, sensor module header) is unchanged from rev 2.

## Decision drivers

- **Uniformity across all deployments.** Same MCU, same protocol, same firmware, same parts. Simplifies development, service, debugging, inventory, and operator training.
- **Minimize design surface area we own.** Where open-hardware modules with the right characteristics exist, use them and concentrate our design effort on integration concerns rather than re-implementing well-known reference designs.
- **Stateless gateway.** Persistent local state on the gateway is a liability (write-amplification, lost-on-replacement, dual-storage forensic surface). Anything that doesn't have to live on the gateway lives in IndustryFlow.
- **Modularity at field level.** Replacing a sensor must not require reconfiguring the bus, the gateway, or the platform.
- **Determinism.** Some loops are safety-relevant. Their messages must not be starved by telemetry.
- **Fault containment.** A short or stuck node must not silence the bus.
- **Mainstream MCU and predictable supply.** Deep ecosystem support, many distributors, no single-vendor lock-in. Pin-compatible drop-in options provide an additional hedge.
- **Furniture-grade installation.** Wiring must be clean. One twisted pair through the cabinet, not a star of cables to a hub.
- **Existing competence.** STM32, embedded C, real-time control are tools already in use.

## Decision

1. **Protocol: Cyphal as application-layer.** Open under Apache 2.0; the DSDL types live in `industryflow.greenhouse.*` (ADR-0005).

2. **Smart-node hardware: WeAct STM32F4 64-Pin Core Board on carrier PCB.** Primary MCU: **STM32F405RGT6** (168 MHz Cortex-M4F, 192 KB RAM, 1 MB Flash, 2× bxCAN). Drop-in fallback MCUs in the same WeAct socket: **STM32F412RET6** and **STM32F446RET6**. The core board provides MCU + HSE/LSE crystals + power conditioning + USB DFU programming + reset/boot controls. Hardware design is open under upstream's repository license. The project keeps a versioned snapshot of WeAct's schematic and gerbers in its own hardware reference repo for resilience against upstream loss.

3. **Carrier PCB design — integration-only board.** The carrier hosts:
   - Socket(s) matching the WeAct STM32F4 64-Pin Core Board pinout
   - Microchip ATECC608B secure element populated on every board, for hardware identity (PKI per ADR-0007)
   - CAN transceiver (NXP TJA1051T/3 or TI SN65HVD230, 3.3 V tolerant)
   - Termination jumper (120 Ω, populated only on the two physical bus ends)
   - Sensor-module header (pinout per ADR-0014)
   - CAN bus connectors (Molex Micro-Fit 3.0 4-pin, IN and OUT)
   - Power input (12 V or 24 V via barrel jack; local TPS54302 buck supplies 3.3 V — the only on-carrier rail — to the ATECC608, bus pull-ups, and the WeAct core board)
   - Status LED for CAN activity
   - ESD protection on the CAN bus

   Likely 2-layer PCB, ~60–70 × 40–50 mm. Schematics, gerbers, and BOM published under CERN-OHL-S.

4. **Hardware reference repository policy.** The project's hardware reference repository contains:
   - Our carrier PCB schematic + gerbers + BOM under CERN-OHL-S.
   - A snapshot of the WeAct STM32F4 64-Pin Core Board schematic + gerbers at a known-good version, retained under upstream's open-hardware license with provenance attribution.

5. **Firmware: static personality with modular driver structure.** Each node type ships its own firmware binary that knows its sensor module. Internally, sensor and actuator drivers conform to a common interface so that migration to dynamic personality (one firmware, type read via sensor-module strap pins) requires only an initialization-stage addition, not an architectural rewrite. Reference firmware under AGPL-3.0-or-later.

6. **Gateway: Raspberry Pi with isolated 2-channel CAN HAT (reference).** Any Raspberry Pi model with SPI-accessible 40-pin GPIO header and supported SocketCAN MCP2515 driver works:
   - **Minimum (apartment-scale): Raspberry Pi 3B+** with 1 GB RAM. Adequate for headless Pycyphal-asyncio gateway servicing one cabinet's 5–10 nodes at the 500 kbit/s classic-CAN rate (decision 8). Headless Pi OS Lite, no GUI, no local storage-heavy services.
   - **Recommended (commercial / higher-traffic): Raspberry Pi 4 (2 GB+) or Pi 5 (4 GB+)** for headroom and NVMe-attached storage. Pi 5's PCIe NVMe slot is useful for production gateways that may host additional edge services in the future.
   - **Industrial enclosures (commercial managed deployments):** RevPi, Compulab, or equivalent — same SocketCAN + Pycyphal software stack, different mechanical/thermal envelope.

   Reference HAT: 2-channel isolated CAN HAT (MCP2515 controllers + SN65HVD230 transceivers, with galvanic isolation). Two channels — one for the cabinet bus, one reserved for future safety-bus separation or debug. Note: the same `SN65HVD230` transceiver is used on the carrier PCB per decision 3 — consistent CAN-PHY across gateway and nodes.

   Gateway service in Python with asyncio, using Pycyphal for protocol handling and Nunavut-generated bindings for DSDL types. **In-memory ring buffer (bounded, default 100 MB) for resilience against transient network loss** — *not* persistent across reboots; reboot-during-outage data loss is accepted as the operational cost of stateless-edge architecture (see ADR-0004 rev 1 for full rationale).

7. **Security boundary at the gateway.** The CAN domain inside the cabinet is explicitly a trusted zone. No per-node authentication on the bus. The boundary between CAN and the outside network is enforced at the gateway. PKI specifics in ADR-0007; host hardening and stateless-edge operational disciplines in ADR-0004 rev 1.

8. **Physical layer:**
   - Linear bus topology, no stars.
   - **Bus bit rate: 500 kbit/s (classic CAN).** A single fixed rate for all nodes and the gateway — no run-time negotiation. 500 kbit/s gives ample headroom for a cabinet's 5–10 nodes while keeping bus length generous (well over the ~100 m a classic-CAN bus at this rate supports, far beyond any cabinet/zone run). Higher rates (1 Mbit/s) shorten the maximum bus length and tighten transceiver/stub-length margins for no throughput need at this node count; lower rates waste headroom. CAN FD is out of scope (decision rejected in F).
   - 120 Ω termination at the two physical endpoints of the bus only.
   - Shielded twisted pair (CAT6 STP is acceptable substrate). Shield grounded at one point near the gateway.
   - Separate power rail (12 V or 24 V), per-node TPS54302 buck (steps the rail to 3.3 V). Bus pairs carry signal only, no power.

9. **Domain mapping.** Each Cyphal node belongs to exactly one IndustryFlow `module` within the cabinet `machine`. Subject-IDs identify *what data*; Node-ID identifies *which physical node*; gateway resolves Node-ID → module assignment via configuration. Tagging by `production_unit_id` (slot) is applied at the gateway based on node-to-slot mapping, not encoded in the CAN frame.

10. **WeAct publishes no gerbers and no licence** *(added 2026-08-15)*. Decisions 2 and 4 assume both. The snapshot is what upstream does publish — V1.1 schematic, V1.1 board outline, V1.0 STEP — filed as `store/SP0005-D-coreboard-snapshot.zip` (`REGISTRY.md`) with WeAct copyright and `LicenseRef-WeAct-unstated`, not the project's CERN-OHL-S default. Decision 2's board selection and decision 4's retention requirement stand.

11. **The gateway is the bus time-synchronization master** *(added 2026-08-25)*. It publishes `uavcan.time.Synchronization` (fixed subject 7168) at `Immediate` priority, at least once per second, and it is the only master on the bus. *At least*: the type's `MAX_PUBLICATION_PERIOD` of one second is a ceiling on the interval, and a slave discards the message pair whenever two arrive further apart than that, so a master targeting exactly 1.000 s loses roughly half its refreshes to ordinary scheduling jitter. The implementation publishes inside the ceiling, not on it. Every node is a slave and fills the `uavcan.time.SynchronizedTimestamp` field of its telemetry from that base.

    Three constraints make this workable rather than nominal:
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

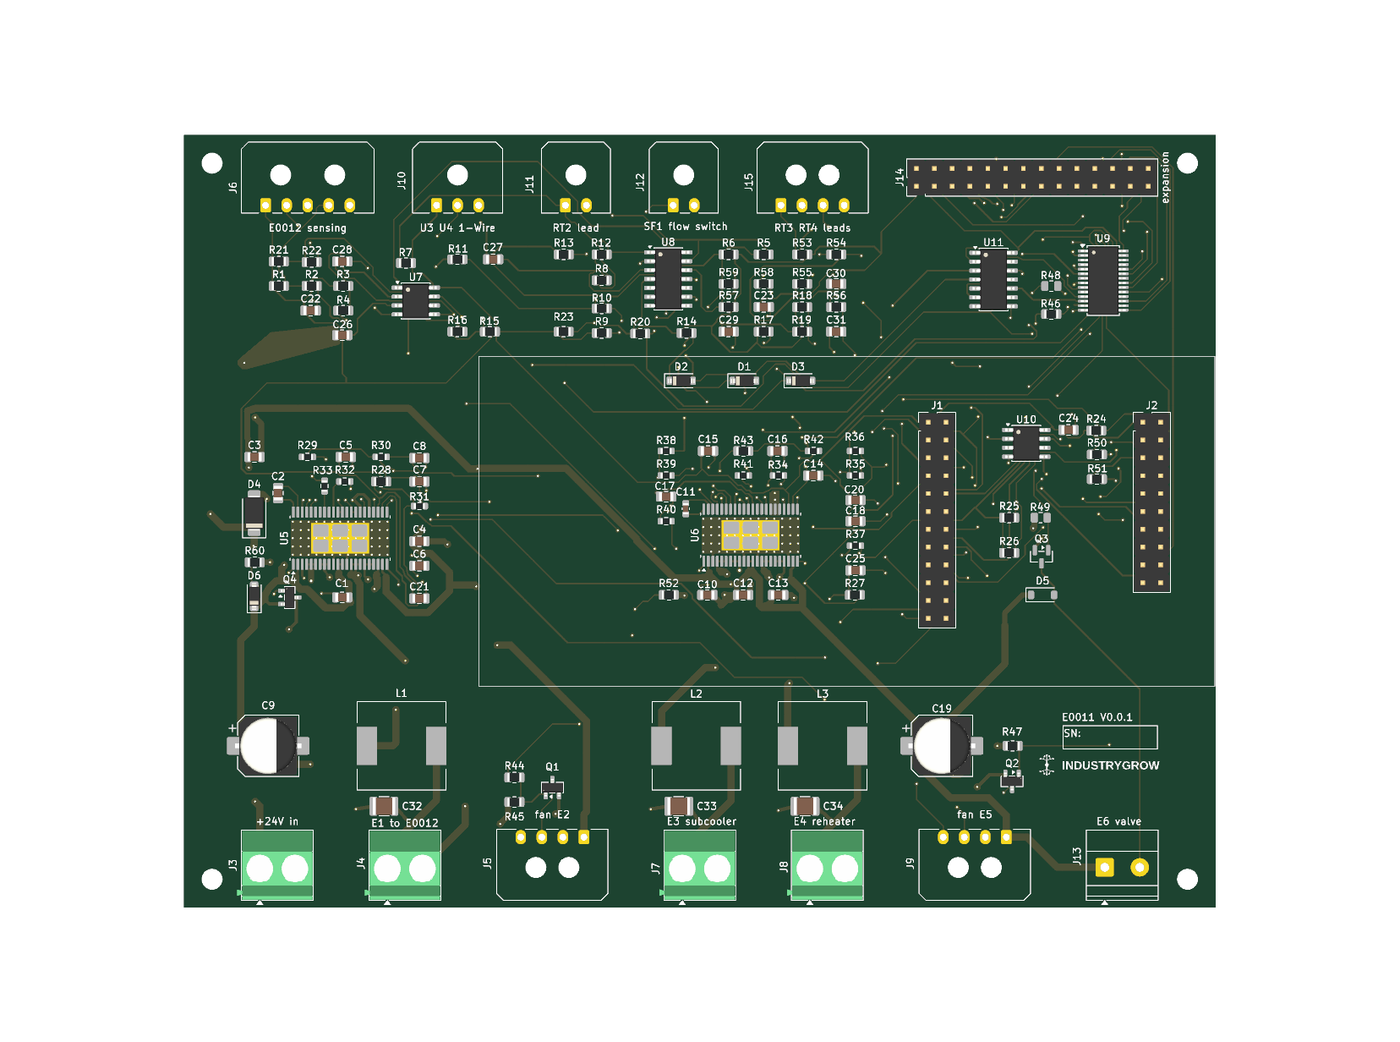
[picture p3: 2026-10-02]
store/E0011-000001-D.png

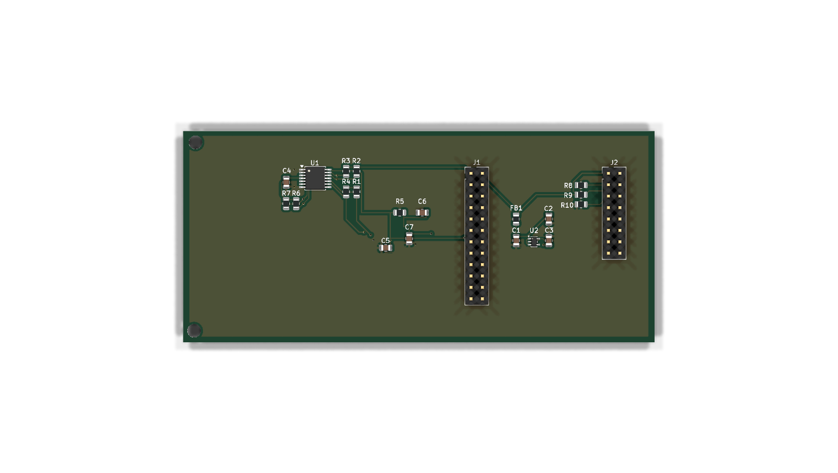
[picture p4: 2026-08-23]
store/E0003-000001-D.png

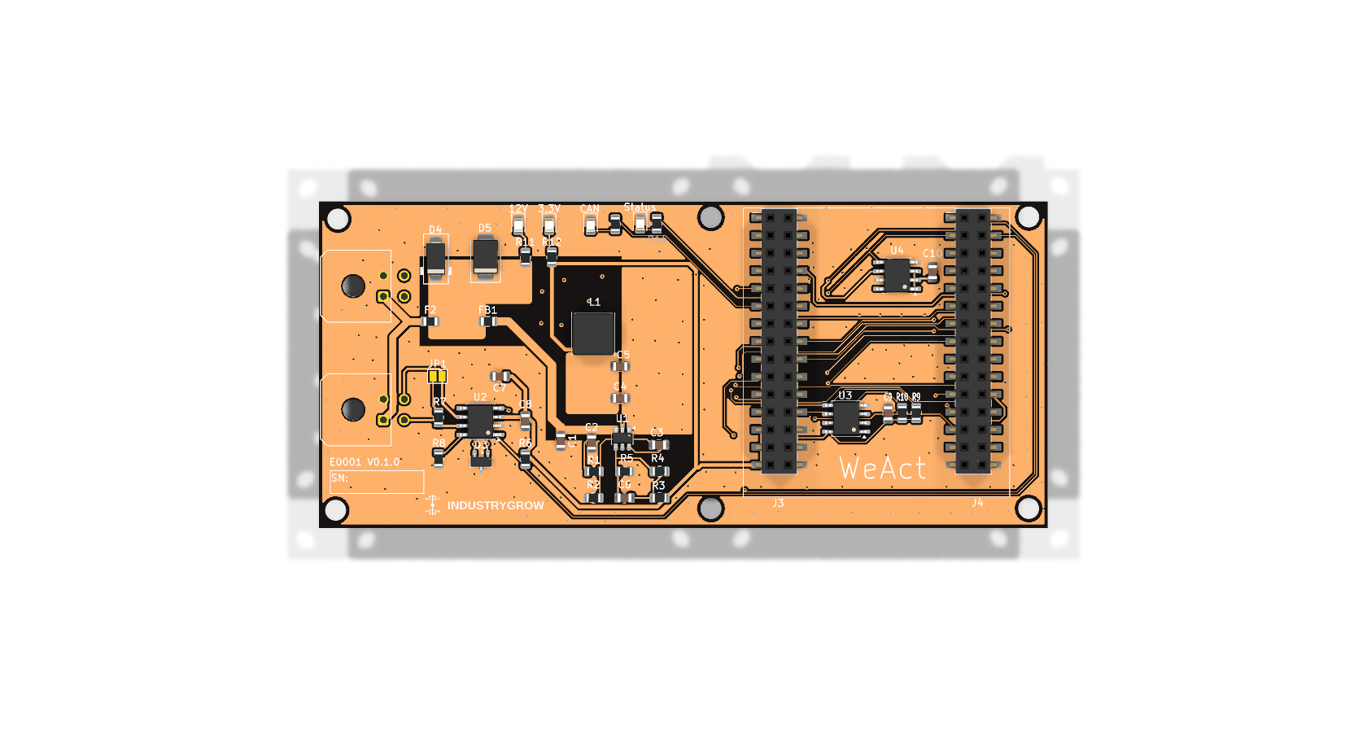
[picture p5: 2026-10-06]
store/E0001-000100-D.png

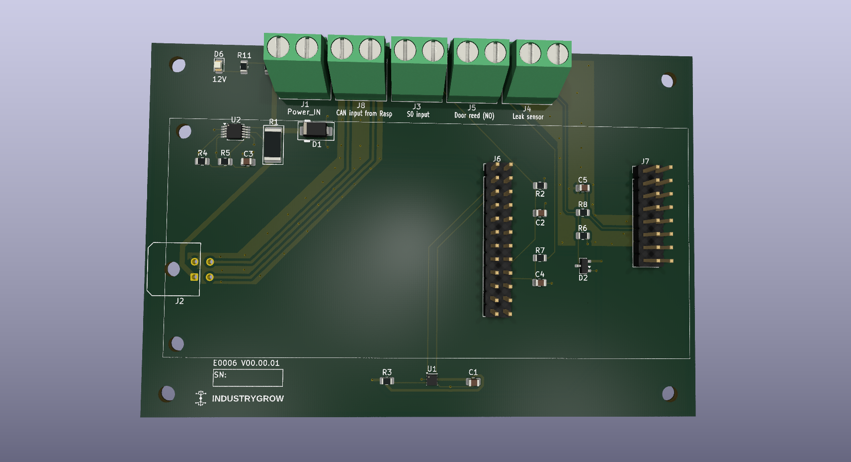
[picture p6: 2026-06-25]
store/E0006-000001-D.png

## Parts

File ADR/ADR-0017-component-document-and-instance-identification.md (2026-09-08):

<!--
SPDX-FileCopyrightText: 2026 The IndustryGrow contributors
SPDX-License-Identifier: CC-BY-SA-4.0
-->

# ADR-0017 (rev 3): Component, document, and instance identification scheme

- **ID:** ADR-0017 (rev 3)
- **Status:** Accepted
- **Date:** 2026-06-19 (rev 2: 2026-08-03; rev 3: 2026-08-30)
- **Project:** IndustryGrow
- **Parent:** ADR-0001
- **Companions:** ADR-0002 (rev 3), ADR-0004 (rev 1), ADR-0007, ADR-0014 (rev 3), ADR-0015, ADR-0016
- **Supersedes:** ADR-0017 rev 2 (2026-08-03), and through it rev 1 (2026-06-19) and the initial record (2026-05-31)

## Revision history

- **Amendments** — decision 20 (2026-09-08): the specification document layer `R`, rooted on the E-number and carrying no version. Extends decision 9's layer set as decision 16 did for `F`; reverses nothing.
- **rev 3 (2026-08-30)** — Editorial. **No decision changes and none is renumbered**;
  the record is cited by decision number across the corpus.

  Removed duplication: the serial's no-overflow rule, argued in decisions 1 and 8 and
  again in alternative D, now stands once in alternative D, where a rejected option
  belongs. Decision 15's block quotes summarising decisions 17–19 now defer to them —
  a summary of a rule goes stale when the rule is amended, which is what ADR-0022
  rev 2 had to correct in its own decision 1. Three paragraphs recording that
  decisions 17–19 were in-place amendments duplicated this revision history. The
  ADR-owns-why / registry-owns-what division, stated four times, is stated once at
  the head of the decision. Decision 4's M07 case is two bullets rather than four.

  Structural: `## Decision` was empty and the numbered decisions sat under
  `## Conceptual model`, which does not contain them.

- **rev 1 (2026-06-19)** — Adopts the firmware document layer `F` into the scheme
  (previously a maintainer-call extension recorded only in `REGISTRY.md`) and
  **roots it on the carrier `E0001`, not the node module**. The firmware is one
  codebase shared by every node type (ADR-0002 d5), selected at runtime by the
  module-ID strap; its version tracks that single carrier-level codebase, so
  filing it per-module (the prior `E0006-…-F` convention) would force one shared
  code change to bump the `F` version of every module — a count-into-identity
  leak. Adds decision 16 and alternative G. Also refreshes companion references:
  ADR-0005 and ADR-0007 are now Accepted (were "planned").
- **rev 2 (2026-08-03)** — Extends the type vocabulary from `M01–M05` to `M01–M07`
  following ADR-0014 rev 2, which adds M06-VENTILATION and M07-AMBIENT. No
  identifier format changes and no decision is reversed; the scheme absorbed two
  new module classes exactly as designed. Decision 4 gains the case ADR-0014 rev 2
  created and this ADR had already answered in principle: M07's indoor and outdoor
  deployment variants are **one bare design and two assembly E-numbers**, because a
  wind group fitted or omitted at build is a real populate variant, unlike the
  carrier's install-time jumper. Also records a gap this revision cannot close —
  the position axis roots every node in a `GBOX_NNNN` cabinet, and an outdoor
  M07 sits in no cabinet while serving several; the missing piece is an entity
  above the machine, which belongs to ADR-0008.

**Amendments** (bounded in-place additions under ADR-0000 decision 9 — each adds a
numbered decision, reverses nothing, and qualifies decision 15):

- **decision 17 (2026-06-21)** — A withdrawn design artifact set is archived as one
  object whose key names its status, `BLOCKED` or `SUPERSEDED`.
- **decision 18 (2026-07-18)** — The live fabrication package (gerber layer set plus
  drill files) is one object, `Exxxx-VVVVVV-D-fab.zip`.
- **decision 19 (2026-08-22)** — The editable design sources of a board version are
  packaged by document layer, `Exxxx-VVVVVV-S-src.zip` and `Exxxx-VVVVVV-D-src.zip`,
  closing the gap that had them stored with no layer letter at all.

## Context and problem

IndustryGrow produces physical artifacts and documentation across a lifecycle (design → production/QC → integration → operation) and across deployment scales (apartment cabinet to commercial greenhouse). The architecture already commits to a strong shape: a small set of reusable PCB designs (carrier, M01–M07 per ADR-0014 rev 2), instantiated many times, with instances that **move between deployments** as inventory (ADR-0016). What it has not committed to is how those artifacts and their documents are **identified**.

The existing ADRs supply a taxonomy — module classes M01–M07, module-ID straps, the carrier as a distinct host board — but not material numbers, serial numbers, document identifiers, or a way to address per-instance lifecycle documents (test data, calibration, provisioning). Without a scheme, traceability is ad-hoc, procurement and QC records have no canonical key, and the inventory/mobility model of ADR-0016 has nowhere to hang an instance's history.

This ADR specifies a hierarchical identification scheme for IndustryGrow. Its organizing principle is the separation of three things the project needs kept apart: the **type** (a module designation plus a version), the **instance** (a serial number), and the **position in the machine** (a hierarchical depth code). The scheme uses phase-specific identifier formats so that an artifact's identifier reflects where it is in its lifecycle, and it reserves a suffix slot for per-instance lifecycle documents.

The separation is load-bearing for two reasons specific to IndustryGrow. ADR-0014 requires that one design be instantiated many times (designs few, instances many); ADR-0016 requires that an individual instance physically move between positions and deployments while keeping its identity and history. An identifier that fused type with position, or instance with position, would break both. This ADR also fixes the bindings that connect the scheme to the rest of the architecture: the instance serial to the ATECC608 hardware identity (ADR-0007), the document interface layer to Cyphal/DSDL (ADR-0002/0005), the integration-phase depth code to the gateway's runtime position tagging (ADR-0014 decision 7), and the suffix set to IndustryGrow's actual per-instance documents — together with the boundary between those documents and IndustryFlow's operational audit log (ADR-0004 rev 1). Rev 1 adds one further binding: the firmware document layer to the single shared codebase that runs on the carrier, so firmware identity follows the carrier (`E0001`), not the node personality (decision 16).

## Decision drivers

- **Reuse the existing taxonomy; do not reinvent it.** M01–M07 and the module-ID straps (ADR-0014 rev 2) are already a stable type vocabulary. The identifier scheme must encode that vocabulary, not run parallel to it.
- **Separate type, instance, and position.** Load-bearing because of ADR-0014 (one design, many instances at many positions) and ADR-0016 (an instance physically moves between positions and deployments over its life).
- **Reuse hardware identity already present.** Every carrier carries an ATECC608 (ADR-0002 rev 3 decision 3). Instance identity should bind to it rather than to a second, invented serial authority.
- **One scheme across disciplines.** Electrical, mechanical, and pneumatic/fluidic parts of IndustryGrow should share one identification scheme, not fork per discipline.
- **Do not duplicate the operational audit trail.** IndustryFlow already holds firmware events, telemetry, and forensic history (ADR-0004 rev 1). The document store must not become a second, divergent record of the same things.
- **Lifecycle documents belong to the instance, not the position.** A board's test, calibration, and provisioning history must follow its serial across re-installations.

## Decision

### Conceptual model (governing invariant)

Identity has two orthogonal axes that never fuse:

- **Identity axis** — *what a thing is, and which copy.* Rooted at the
  E-module: `Exxxx → VVVVVV → NNNNNN`. Assigned at design / production.
  Position-free.
- **Position axis** — *where a thing physically sits.* Rooted at the machine:
  `GBOX_NNNN → DDDDDD`. Assigned at integration. Identity-free.

The axes meet only in the integration identifier
`GBOX_NNNN-DDDDDD-Exxxx-VVVVVV-NNNNNN`, a *mutable cross-reference* re-assigned
whenever an instance is moved, removed, or replaced. A serial never encodes
position; a position never encodes identity.

A third notion — the **document layer** (`S/D/L/P/M/I`, plus `F` for firmware,
decision 16, and `R` for a specification, decision 20) — is not an axis but a
classifier on the identity axis (which artifact about a given identity); it never
denotes nesting.

Every numbered decision below is a consequence of this invariant. The rejected
alternatives (flat hierarchical serial; position baked into serial) are exactly
the collapse of these two axes into one, which the invariant forbids because
instances are mobile and interchangeable (ADR-0014, ADR-0016).

> Terminology for this ADR is governed by `GLOSSARY.md`.

This record holds the *why* and the form of every identifier below. The *what* —
which concrete object exists under which key, each withdrawal's file boundary,
each package's member list — is `REGISTRY.md`'s (ADR-0000 d2). Procedures are
`CONTRIBUTING.md`'s. Neither is restated here.

Two identity trees joined at integration

### Identifier formats

1. **Three phase-specific identifier formats.**
   - Documentation (design artifacts, type-level): `Exxxx-VVVVVV-L`
   - Production & QC (a manufactured instance): `Exxxx-VVVVVV-NNNNNN[-suffix]`
   - Integration (an instance installed in a machine): `GBOX_NNNN-DDDDDD-Exxxx-VVVVVV-NNNNNN`

   Decoded:

   ```
   Documentation  (type-level)
   Exxxx-VVVVVV-L
   │     │      │
   │     │      └─ document layer (S, D, L, P, M, I, F)
   │     └─ version, 6 digits (major.minor.patch)
   └─ module, E + 4 digits

   Production & QC  (one manufactured instance)
   Exxxx-VVVVVV-NNNNNN-XX
   │     │      │      │
   │     │      │      └─ lifecycle suffix (QP, QR, CP, CC, PR)
   │     │      └─ serial, 6 digits (per module + version)
   │     └─ version, 6 digits
   └─ module, E + 4 digits

   Integration  (instance installed in a machine)
   GBOX_NNNN-DDDDDD-Exxxx-VVVVVV-NNNNNN
   │         │      │     │      │
   │         │      │     │      └─ serial (from production)
   │         │      │     └─ version, 6 digits
   │         │      └─ module, E + 4 digits
   │         └─ depth, 6 digits (position in machine)
   └─ machine, GBOX + 4 digits

   Two encoded fields carry sub-structure:
   VVVVVV  =  major.minor.patch   (2 digits each)        e.g. v2.1.3 = 020103
   DDDDDD  =  main.sub-L1.sub-L2  (2 digits each, main 01–99)
              e.g. climate node at position 1.1 = 010100
   ```

   Field definitions:
   - **Module** `Exxxx` — `E` plus four digits; identifies a buildable/documentable assembly (decision 3). An opaque key; meaning is held in the registry.
   - **Version** `VVVVVV` — six digits encoding semantic version `major.minor.patch`, two digits each (`1.0.0` → `010000`, `2.1.3` → `020103`). This is the version of the *design*, not of a populated configuration (see alternative D).
   - **Serial** `NNNNNN` — six digits, unique per module+version (`000001`–`999999`). Assigned in Production. The width is sized to the largest declared deployment's lifetime install base of a single design+version — most acutely the universal carrier, which has one near-static version and therefore accumulates the most serials. A full range is widened, never overflowed into the version (alternative D).
   - **Depth** `DDDDDD` — six digits in three two-digit levels (main / sub-position 1 / sub-position 2), encoding the position within the machine hierarchy. Position only; assigned at integration, never present in the production identifier (decision 7).
   - **Document layer** `L` — a single letter naming the document type (decision 9, extended by decision 16).
   - **Suffix** — a per-instance lifecycle-document tag appended in the production identifier (decisions 10–14).

   Documents are stored flat, the hierarchy carried entirely in the identifier, so the store is filtered by identifier pattern — all documents of one module, all reports, all instances at a given position. Decision 15 fixes the backend this implies.

2. **Two distinct instance histories, one of which this ADR governs.** Static, per-instance *documents* (test data, calibration, provisioning records) live in the document store and are addressable by suffix. *Operational/runtime events* (firmware-flash events, telemetry, control-decision audit, hash-chain) live in IndustryFlow's audit log per ADR-0004 rev 1 decisions 10 and 16. The two are not merged and not duplicated. Suffixes (decisions 10–14) address only the former.

### Code legend

The single key to every code that can occupy the trailing slot of an identifier: the **document-layer** letter in the type-level form `Exxxx-VVVVVV-L` (e.g. the `D` in `E0001-000001-D.png`, the `L` in `E0001-000001-L.csv`), the **lifecycle suffix** in the instance form `Exxxx-VVVVVV-NNNNNN-XX`, the **status token** of a withdrawn artifact set (decision 17), and the **package descriptor** of a document-layer object that collapses a set into one file (decision 18). This table is the one place the codes are expanded; the cited decisions hold the definitions and rules, not a second copy of the mapping. The sets are extensible — add a code by appending a row here. Suffix codes are two uppercase letters and must not collide with the document-layer letters; status tokens are full uppercase words, so they can collide with neither.

| Code | Meaning | Field | Defined in |
|---|---|---|---|
| `S` | Schema | document layer | decision 9 |
| `D` | Drawing | document layer | decision 9 |
| `L` | List / BOM | document layer | decision 9 |
| `P` | Protocol | document layer | decision 9 |
| `M` | Manual | document layer | decision 9 |
| `I` | Interface | document layer | decision 9 |
| `F` | Firmware (built image + source snapshot) | document layer | decision 16 |
| `R` | Requirements (specification) | document layer | decision 20 |
| `-QP` | Quality Protocol | lifecycle suffix | decision 10 |
| `-QR` | Quality Report | lifecycle suffix | decision 10 |
| `-CP` | Calibration Protocol | lifecycle suffix | decision 11 |
| `-CC` | Calibration Certificate | lifecycle suffix | decision 11 |
| `-PR` | Provisioning Record | lifecycle suffix | decision 12 |
| `BLOCKED` | Withdrawn artifact set — defective, never to be fabricated or relied on | status token | decision 17 |
| `SUPERSEDED` | Withdrawn artifact set — replaced, no defect | status token | decision 17 |
| `-fab` | Fabrication package: the gerber layer set plus drill files, one object | `D`-layer package descriptor | decision 18 |
| `-src` | Design-source package: the editable CAD files of one document layer, one object | `S`- / `D`-layer package descriptor | decision 19 |

### Module designation (E-numbers)

3. **An E-number identifies a buildable/documentable assembly.** The existing taxonomy maps directly: the carrier and each of M01–M07 are buildable assemblies and each receives an E-number. A **functional subsystem** (climate, lighting, irrigation, plant monitoring, pollination, power/safety per ADR-0001 decision 7) is *not* an E-number — it is a **position** in the machine, expressed as a depth code (decision 7). The WeAct STM32F4 core board is a purchased sub-component identified by an `SP` number, not an E-number (ADR-0019). One further bounded carve-out: a *designed* accessory that has no existence apart from one specific part (a printed case, a bracket, a mount) does **not** take its own E-number — it rolls up under the served part's root as a `D`-layer document (ADR-0019 decision 9); a designed assembly that stands alone or is serialized still does (decision 4, decision 5).

4. **Bare-PCB design and populated assembly are distinguished.** One PCB *layout* is one bare-board design artifact; each standard *populated configuration* of that layout is an assembly E-number that references the shared bare design. This resolves the partial-BOM mechanism of ADR-0014 decision 2 without adding a variant field to the scheme:
   - **Carrier:** one bare design and effectively one assembly. Termination is jumper-selected and the power-input set is the only populate option, so the carrier is treated as a single assembly E-number — one type, one version, many serials, appearing at many depth positions. (This was the original motivating case: the carrier is universal precisely because it has no real variant.)
   - **M01–M07:** one bare design each, and one fully-populated assembly E-number each as first assigned — which is what the Phase-1 set M01–M05 carries today. Zone-specific partial populations (ADR-0014 decision 2) receive **additional assembly E-numbers referencing the same bare design** — no new layout, no version churn.
   - **M07's indoor and outdoor variants are two assembly E-numbers, not one** *(rev 2)*. ADR-0014 rev 2 gives M07 two deployment variants sharing one layout, one module-ID strap and one firmware image, differing only in populated BOM and housing. That is precisely the case this decision resolves, so it resolves it the same way: **one bare design, two standard populated configurations, therefore two assembly E-numbers.** The outdoor variant populates a wind group — pulse conditioning, shift-register interface, heading reference — that the indoor variant leaves as bare footprints. Two boards you order, stock, build and serialize differently are two things on the identity axis, whatever they share on the design axis.
     - **The carrier's single-assembly treatment does not extend to M07.** The carrier is one assembly because its only populate option is a jumper set at install time; a wind group fitted or omitted at build is a real variant.
     - **One module class, two assembly numbers is not a contradiction.** ADR-0014 rev 2 is right that M07 is not two module *classes* — one strap value, one image, because a node identifies its class and the boot probe finds what is fitted (ADR-0014 d8). Class and assembly are questions on different axes. The second number is assigned at design commit, not reserved now (decision 5).

5. **Discipline (electrical / mechanical / pneumatic / fluidic) is a property of the E-module, not a field in the identifier.** It is expressed through decomposition — each discipline-specific buildable unit is its own E-number at its own depth sub-position — and recorded as registry metadata. The identifier stays opaque, with meaning held in the registry. Encoding discipline by partitioning the E-number range (e.g. reserving leading digits per discipline) is **reserved as an option** for the case where pattern-filtering by discipline across the document store becomes necessary; it is not the default.

### Machine designation and position

6. **The cabinet machine (ADR-0001 decision 7) is designated `GBOX_NNNN`** (Grow Box). The machine designation has the general form `<prefix>_NNNN` — four digits, enumerating grow-cabinets across the product (a deployment-scaling field, sized like the serial against the largest declared deployment rather than a single apartment cabinet). The `GBOX` prefix is specific to IndustryGrow grow-cabinet machines, leaving room for other machine families under their own prefixes should the scheme be reused elsewhere.

7. **The integration-phase depth code is the static twin of gateway-side position tagging.** The depth code encodes the same information the gateway resolves at runtime as `(module_class, node_role, zone)` and `production_unit` (ADR-0014 decision 7; ADR-IF-0001, planned). Position is assigned at integration and **never** appears in the production identifier. This preserves instance interchangeability (ADR-0014) and instance mobility between deployments (ADR-0016): the same `Exxxx-VVVVVV-NNNNNN` can be installed at many different depth positions over its life. The depth code's two-digit-per-level width (main `01`–`99`) is intentionally *not* widened with the serial and machine fields: depth is intra-machine, bounded by one cabinet's physical decomposition (~6 functional subsystems per ADR-0001 decision 7), not by deployment size. Scaling a commercial facility means more serials and more `GBOX` machines, each carrying its own depth space — never a deeper hierarchy inside one box. The sizing principle across the scheme is "size to the largest declared deployment," and for depth the largest single machine is already covered with wide margin.

### Instance identity

8. **The serial number is the logistics instance key; the ATECC608 is the cryptographic instance identity.** The serial (decision 1) is the human- and store-facing instance key. The durable cryptographic identity is the ATECC608 plus its provisioned certificate (ADR-0007). The two are bound to each other in the provisioning record (decision 12); no separate serial authority is invented. Serials are assigned in Production (Phase 2).

### Document layers

9. **Document-layer set `S` / `D` / `L` / `P` / `M` / `I`** — expanded in the code legend above. Two IndustryGrow-specific bindings: the **`I` (Interface)** document layer carries Cyphal subject-ID assignments and DSDL `industryflow.greenhouse.*` type definitions (ADR-0002 rev 3 decision 1; ADR-0005); the **`L` (List)** document layer carries the per-module BOMs already drafted in the procurement and sensor-module documents. **Rev 1** extends the set with **`F` (Firmware)** — the built node image and its source snapshot — whose carrier-rooted addressing is decision 16.

### Suffixes (per-instance lifecycle documents)

10. **`-QP` / `-QR`.** `-QP` (Quality Protocol) is the raw bring-up and functional-test data for an instance (DFU flash, bxCAN init, Cyphal heartbeat, sensor-presence I²C probing, functional run against bench stimuli). `-QR` (Quality Report) is the evaluated result and acceptance. Discipline-specific test content (dimensional inspection for mechanical, leak/pressure test for pneumatic) lives *inside* the QP document; the suffix code stays generic. No `QP`-electrical / `QP`-pneumatic proliferation.

11. **`-CP` / `-CC`, mirroring the protocol/report pattern.** `-CP` (Calibration Protocol) holds the raw calibration points; `-CC` (Calibration Certificate) holds the resulting coefficients and validity period. Primary driver is M03-ANALYTICS (pH against buffers 4/7/10, EC against 1413 µS/cm) plus any sensor offset trims. Unlike QC, **calibration recurs** (probe drift, scheduled recalibration), so calibration suffixes are dated or sequenced — `-CC-YYYYMMDD` or `-CCnnn` — so a later calibration does not overwrite an earlier record. Deployment-level model calibration (ADR-0016 state-space identification) is explicitly *not* a calibration suffix; it is profile-versioned per ADR-0015 (see decision 13 and the alternatives).

12. **`-PR` (Provisioning Record).** Binds the ATECC608 to its issued certificate and holds the certificate metadata (ADR-0007) — the instance's "birth certificate." It contains the public material only; the private key never leaves the ATECC608. Restricted to engineering/quality access.

13. **Suffixes attach to the instance identifier, never to the integration identifier.** Lifecycle documents key off `Exxxx-VVVVVV-NNNNNN`, which is stable; the integration identifier merely records where the instance currently sits and changes when the instance is moved. This is mandatory under ADR-0016's inventory model: when a board is redeployed, its QP/QR/CP/CC/PR history follows its serial, and a recalibration at the new deployment adds a new dated `-CC` to the same serial — not a record on the new position.

14. **M03 probes are their own instances.** The pH electrode and EC cell are replaceable consumables with independent drift and replacement life, so each is its own E-number with its own serial and its own calibration history. The M03 board's calibration record references the paired probe serial, so the board+probe pairing and the probe's standalone history are both reconstructible.

### Storage backend and object-store mapping

15. **The document store is an object store; identifiers are object keys.** The flat layout (decision 1) is chosen for object storage (S3-compatible buckets), not a hierarchical filesystem. Each artifact is a single object whose key *is* its identifier (`E0001-000001-L.csv`, `E0001-000001-D-Top_Layer.gtl`, a `-CC-YYYYMMDD` calibration certificate, and so on); there are no container objects and no real directories. The identifier-pattern filtering of decision 1 *is* the bucket's prefix listing (`ListObjectsV2(Prefix=…)`), executed server-side with no separate index to maintain. The object-store mechanics this enables — on-demand hierarchy synthesis via a delimiter, write-once / versioning for the immutable QC and provisioning records, and prefix-scoped retention and access policy — are deployment specifics (see Deferred decisions); a git checkout renders the same flat keyspace as a flat directory, which is incidental.

    > **Bounded exceptions.** Three sets collapse to one object each, and each states its own scope and reason: withdrawn artifact sets (decision 17), the fabrication package (decision 18), and the design-source packages (decision 19). One-object-per-identifier holds for everything else. Those decisions are not summarised here — a summary of a rule goes stale when the rule is amended, and this is the decision the summary would contradict.

### Firmware document layer

16. **The firmware document layer `F` roots on the carrier (`E0001`), not the node module.** The node firmware is a single codebase (`firmware/`) shared by every node type — `common/` is the carrier support, `nodes/<type>/` are personalities selected at runtime by the module-ID strap (decision 7; ADR-0014 d6). The personality is a hardware/runtime attribute, not a separate codebase, so the firmware's `F` version tracks the one carrier-level codebase: `E0001-VVVVVV-F[.hex|-src.zip]`. `VVVVVV` is the firmware (codebase) version, independent of the `E0001` *board* design version — a firmware release bumps `F` without re-spinning the carrier PCB. Filing the firmware per-module (e.g. `E0006-…-F`) would make a single change to shared code bump the `F` version of every module that runs it, leaking a code-change count into N module identities — the same corruption decision 8 and alternative D forbid for serial-into-version. If per-type binaries are ever built from this one codebase they are build *variants* of the same versioned source (`E0001-VVVVVV-F-<type>`), not separate `F` roots. The `F` artifacts are reference firmware licensed AGPL-3.0-or-later (ADR-0002 d5), overriding the CERN-OHL-S `store/**` hardware default (`REUSE.toml`).
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

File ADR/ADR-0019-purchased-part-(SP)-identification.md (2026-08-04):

<!--
SPDX-FileCopyrightText: 2026 The IndustryGrow contributors
SPDX-License-Identifier: CC-BY-SA-4.0
-->

# ADR-0019: Purchased-part (SP) identification

- **ID:** ADR-0019
- **Status:** Accepted
- **Date:** 2026-06-13
- **Project:** IndustryGrow
- **Parent:** ADR-0001
- **Companions:** ADR-0017, ADR-0000, ADR-0014, ADR-0018
- **Resolves:** ADR-0017 deferred item "WeAct core board identification"

## Context and problem

ADR-0017 identifies what the project *designs*: the carrier and M01–M07 are E-modules, with an identity axis `Exxxx-VVVVVV-NNNNNN` whose version is our design's semantic version and whose serial is our manufactured, ATECC608-bound instance. It deliberately left open how to identify what the project *buys* — flagging the WeAct core board as "own E-number or vendor-part-number tracking (deferred)" (decision 3).

The gap became concrete with the cabinet power-distribution work (ADR-0018): a power supply, a DIN kWh meter, a fuse-holder, the gateway Raspberry Pi, and — when actuators arrive — pumps, SSRs, fixtures, and heating elements are real cabinet line items that need a stable key for part lists, inventory, and cost accounting. None is a thing we design, version, or serialize; forcing them into the E-number space would fill its version and serial fields with foreign or empty data and corrupt E semantics.

This ADR adds a parallel, deliberately minimal identifier for purchased (COTS) parts. It is a separate record rather than an expansion of ADR-0017, to keep that scheme focused on designed assemblies.

## Decision drivers

- **Designed vs purchased is a real ontological split.** Our version and serial semantics (ADR-0017) apply only to things we design and build.
- **A stable key for cost and inventory.** Part lists and procurement need one key per purchased type to roll up quantity and cost.
- **Spec, not SKU, is the commitment.** The vendor part is swappable; the characteristic it must meet is durable — the pattern ADR-0018 already uses for the kWh meter (S0 contract is the commitment; meter is a swappable line item).
- **Single source of truth (ADR-0000).** The live SKU and price are downstream values in the BOM; the identifier holds the spec, not the order data.
- **No over-engineering.** Not every purchased component earns a number; the catalog stays at procurement/inventory granularity.

## Decision

1. **Purchased (COTS) parts are identified by an `SP` number — `SPxxxx`** (`SP` + four digits): a second type-root on the identity axis (ADR-0017), parallel to the E-module, for things the project buys rather than designs. Like the E-number it is opaque; its meaning lives in the registry. (`SP` = "Supplied Part".)

2. **No project version, no project serial.** The supplier owns versioning, so the SP identifier carries no `VVVVVV` field; it is type-level. Where a purchased unit must be tracked as an individual instance (e.g., the gateway Raspberry Pi), the instance key is the vendor's own serial / device identity recorded in the BOM and, where applicable, the provisioning record — never a project `NNNNNN`.

3. **An SP number names a generic characteristic spec, not a manufacturer part.** The vendor-free spec (what any acceptable part must satisfy) is the authority; the concrete vendor SKU and price live downstream in the `L` (List/BOM) document per ADR-0000. A part may be swapped for any other that meets the spec without changing the SP number — the swappable-line-item pattern ADR-0018 applies to the kWh meter.

4. **Granularity threshold — what earns an SP number.** A purchased item is SP-numbered when it is a unit of procurement, inventory, or cost accounting, or a designated traceable sub-assembly: power supply, DIN kWh meter, gateway Raspberry Pi, pumps, SSRs, fuse-holders, the WeAct STM32F4 core board, and the like. Ordinary purchased components populated onto a project PCB (INA226, TMP117, passives) are *not* SP-numbered; they remain MPN line items inside that board's `L` document. This keeps the SP catalog at procurement granularity and avoids the catalog growth ADR-0017 cautions about for assembly E-numbers.

5. **Position is not encoded in the SP number.** A purchased part is placed by a reference designator in a schematic or cabinet — its position in one document — not by the integration depth code `DDDDDD`. SP items are generally not Cyphal-bus participants, so they have no gateway-side `(module_class, node_role, zone)` twin and no depth code. Identity (what it is) and position (where it sits) stay separate exactly as in ADR-0017.

6. **Designed-vs-purchased boundary for actuators.** An actuator *node* — carrier + actuator-module PCB, our design — is an E-module and receives an E-number when designed (actuator-taxonomy ADR, deferred per ADR-0014 decision 9). The actuator *device* it drives or switches — pump, peristaltic head, LED fixture, heating element, SSR, fan — is purchased and SP-numbered. No SP or E numbers are assigned now: Phase 1 has no actuators, and identifiers are assigned at design/selection commit, not pre-reserved by class (ADR-0017 opaque-identifier principle).

7. **Resolves ADR-0017's WeAct deferred item.** The WeAct STM32F4 core board is a purchased sub-assembly and receives an `SP` number (decision 4); it is not given an E-number.

8. **Purchased parts carry documents on the same document-layer set as E-modules, on the `SP` root and without a version field** *(added 2026-07-12)*. An SP part needs its own documents — a bring-up manual, a BOM, an interface note — and these reuse the document-layer letters `S/D/L/P/M/I` defined for E-modules (ADR-0017 decision 9) rather than a parallel vocabulary. The form is `SPxxxx-<layer>[-<slug>]`, e.g. `SP0004-M-gateway-bringup` (Manual) or `SP0004-L` (BOM). There is **no `VVVVVV` field** — the supplier owns the part's versioning (decision 2), so an SP document is type-level like the SP identifier itself, and a vendor model of one spec (Pi 3B+/4/5) does not fork it (decision 3): one document set per spec, model-specific content as sections. This form was previously a maintainer-call recorded only in `REGISTRY.md` (2026-06-16); it is promoted here because it now underpins decision 9 and constrains identifier tooling (regex parsing, prefix filtering) — the very trigger that registry note named for promotion. `REGISTRY.md` retains only the list of live SP documents (the *what*, ADR-0000 d2); this decision is the form and the *why*.

9. **A designed accessory that serves only one specific part rolls up under that part's root; it does not receive its own E-number** *(added 2026-07-12)*. Some artifacts the project designs and revises — an enclosure, bracket, mount, adapter, gasket — have **no independent existence**: each exists solely to fit or serve **one** specific part, whether a purchased `SP` part or a designed `E` assembly. Such an accessory is filed as a document on the root of the part it serves, on the `D` (Drawing) layer (decision 8; ADR-0017 d9), with a descriptive slug:

   ```
   <parent-root>-D-<slug>[-src].<ext>     e.g.  SP0004-D-rp5-case-src.zip
   ```

   - **Why not its own root.** Two reasons, both consequences of the artifact having no life apart from its parent. *Root economy:* it never appears without the parent, so a standalone E-number multiplies identity with no retrieval benefit — the same anti-proliferation reasoning that keeps vendor variants as BOM lines (decision 3) and populate-variants as assembly-E on a shared bare design (ADR-0017 d4). *Dossier grouping:* the load-bearing fact is *which part it serves*, and encoding it in the key prefix makes the part's whole dossier — its BOM, manual, and accessories — one prefix list (`ListObjectsV2(Prefix="SP0004-")`, ADR-0017 d15), which a relationship buried in registry metadata does not give.
   - **Revisions ride in the slug.** A revised accessory design takes a new slug (`-rp5-case-rev2`), not a version field: a purchased-part root is version-less (decision 2), and even under an `E` parent the parent's `VVVVVV` versions the *parent's* design, not the accessory's independent revision stream. Slug-revisioning is coarser than a semantic version but suffices for the low-churn mechanical accessories this rule covers.
   - **The boundary — when it keeps its own E-number.** The rule is narrow. A designed artifact that stands alone, is used with more than one parent, or is itself instantiated/serialized as inventory is a designed **assembly** and takes its own E-number (ADR-0017 d3/d5) — it is not an accessory. The universal carrier `E0001` *hosts* the WeAct board `SP0005`, and the distribution case `E0007` *houses* the gateway Pi `SP0004`, yet both are standalone, serialized, multi-deployment assemblies — emphatically not accessories to the parts they carry. The test is independence of existence, not physical attachment.
   - **Licensing** inherits the parent artifact's `store/**` default (`REUSE.toml`).

Decisions 8 and 9 are recorded as additive in-place amendments (dated 2026-07-12): a naming rule promoted from a registry maintainer-call (8) and a new identification rule that bounds the designed-vs-purchased split for accessories (9). Neither changes a decision already on record, so per ADR-0000 d5 they are added in place without a revision bump; the maintainer accepts them through review-and-merge (ADR-0000 d7).

## Alternatives considered

**A. Give purchased parts E-numbers** (the "own E-number" option ADR-0017 decision 3 left open). *Rejected:* E's version is our design's semver and E's serial is our ATECC-bound manufactured instance; a purchased part has neither, so the E fields would be empty or foreign and E semantics would erode.

**B. No identifier for purchased parts — track them only as MPN strings in BOMs.** *Rejected:* loses a stable key for cost/inventory roll-up and for referencing one part from several documents; the swappable-spec pattern (ADR-0018 meter) would have nowhere to attach.

**C. Encode the manufacturer or SKU in the SP number.** *Rejected:* binds the identifier to a vendor that is by design swappable. The SKU is a downstream value (ADR-0000); the SP number is the stable spec key above it.

**D. Give every SP instance a project serial.** *Rejected:* most COTS (a fuse) are not individually tracked; where instance tracking matters (the Pi), the vendor's own serial is the instance key. A parallel project serial authority for bought parts is needless.

**E. Give every designed accessory its own E-number** (the strict reading of the designed-vs-purchased split: anything the project designs and versions is an E-module, so a printed case earns an E-number with a first-class `VVVVVV` field, keeping the split pure). *Rejected (decision 9):* it multiplies identity roots for artifacts that have no existence apart from their parent, and demotes the one fact that matters about such an artifact — the part it serves — to registry metadata, forfeiting the single-prefix part dossier. The version field it would buy is met adequately by slug-revisioning for low-churn accessories. This is a deliberate trade of designed/purchased *purity* for root economy and retrieval; decision 9's boundary keeps the trade bounded to artifacts with no independent existence, so a standalone or serialized designed assembly still takes its own E-number.

## Consequences

### Positive

- Cost and inventory roll-up gets a stable per-type key; designed (E) vs purchased (SP) is explicit at a glance.
- The spec-is-the-commitment / vendor-is-swappable pattern (ADR-0018 meter) is now general, not per-component.
- ADR-0017 stays focused on designed assemblies; this lives separately and removes its WeAct deferred item.

### Negative

- A second number space and a second registry section to maintain — mitigated by reusing E's opaque-key + registry pattern.
- The threshold (decision 4) is a judgment that must be applied consistently, or the SP catalog drifts toward either bloat or gaps.
- Spec-not-SKU discipline must be held in the BOM: an SP number must point to a spec a part satisfies, not be quietly treated as a single fixed SKU.
- A designed accessory filed under a version-less `SP` root (decision 9) means `^E\d{4}` no longer enumerates literally every artifact the project authored; "everything about part X" (`^SP0004-`) is the grouping optimized for instead — a deliberate choice (decision 9, alternative E).
- Accessory design-revision history is slug-encoded (`-rev2`) rather than carried in a semantic-version field: coarser, and dependent on slug discipline being held consistently.

## Relationship to other ADRs

- **ADR-0017** — sibling identification scheme; SP is the purchased-part type-root on the same identity axis, and this ADR resolves 0017's WeAct deferred item. SP documents reuse its document-layer set (d9) per decision 8; the designed-accessory carve-out from its E-number rules (d3/d5) is decision 9.
- **ADR-0000** — the live SKU and price stay downstream in the BOM; the SP record holds the spec/decision, not the order value.
- **ADR-0018** — the cabinet whose PSU, meter, and fuse-holder motivated this; the kWh-meter swappable-line-item / S0-contract pattern is the template for spec-over-SKU.
- **ADR-0014** — actuator *boards* are E-modules; the actuator *devices* they drive are SP parts.
- **ADR-0002** — the WeAct STM32F4 core board, previously a "COTS sub-component," is now an SP part.

## Deferred decisions

- Registry **location and tooling** for the `SPxxxx → spec / meaning` map (shares ADR-0017's registry location/tooling question). The `SP` = "Supplied Part" gloss is now confirmed (decision 1) and the repo-side registry section exists (`REGISTRY.md`); only the platform host and tooling remain open.
- Reference-designator convention for cabinet schematics (IEC 81346 letters) — a drafting convention, recorded with the schematic, not here.
- Whether any SP item ever needs a depth code — none does now; revisit only if a purchased item becomes a positioned, tracked machine element.

## References

- ADR-0000: Decision records and single-source-of-truth discipline.
- ADR-0002 (rev 3): Field bus architecture — WeAct core board.
- ADR-0014: Sensor node taxonomy — actuator boards as E-modules (decision 9).
- ADR-0017: Component, document, and instance identification — E-module identity axis; WeAct deferred item.
- ADR-0018 (rev 1): Cabinet power distribution — swappable COTS meter, S0 contract.

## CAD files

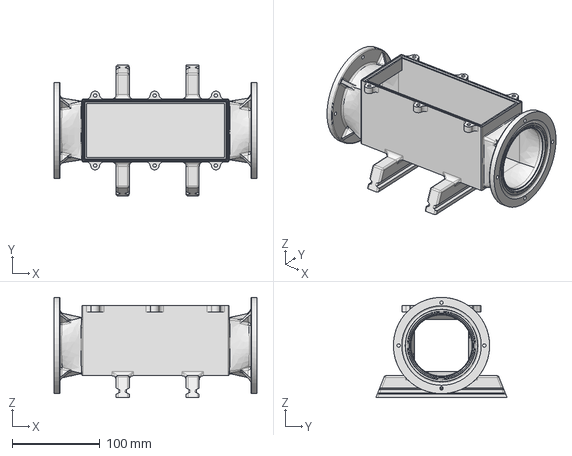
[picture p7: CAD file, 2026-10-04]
project/mechanical/HS1-bottom.stp
232.0 x 150.0 x 114.5 mm

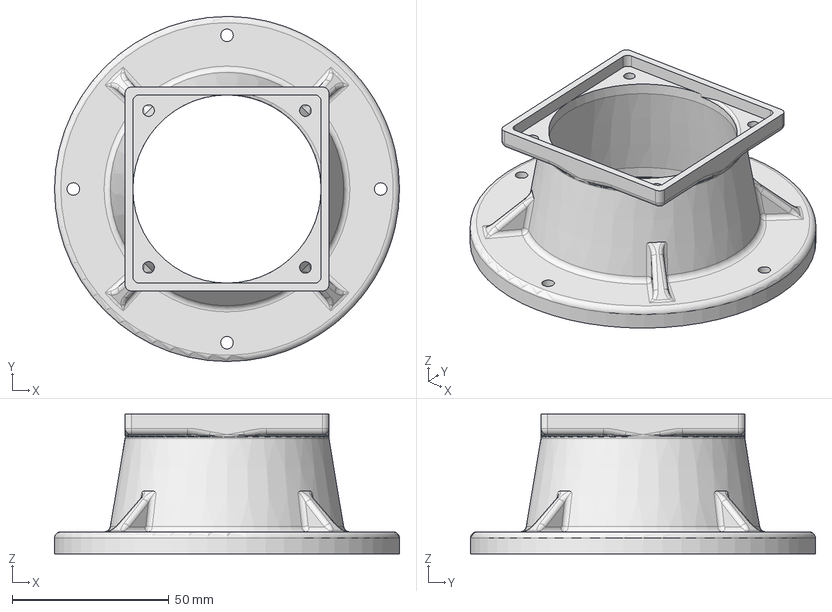
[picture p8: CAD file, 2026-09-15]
project/mechanical/DA1.stp
110.0 x 110.0 x 44.5 mm

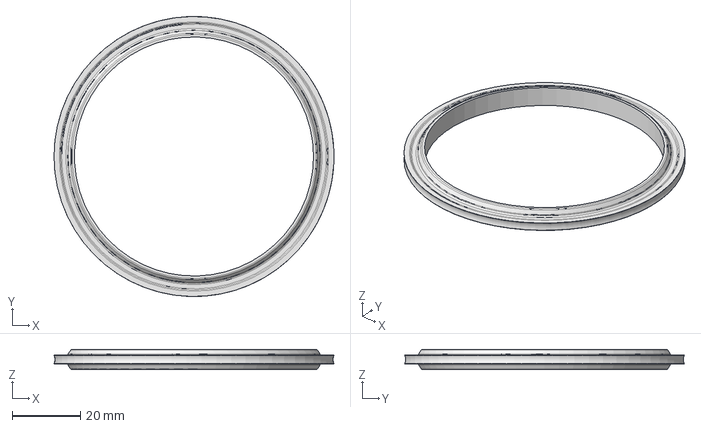
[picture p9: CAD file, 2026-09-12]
project/mechanical/SL1-petg.stp
82.0 x 82.0 x 6.00 mm

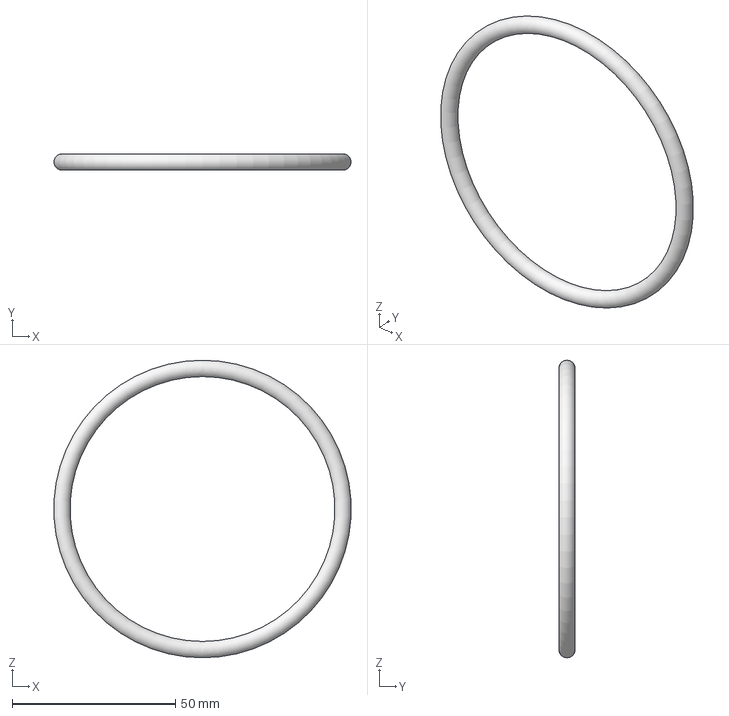
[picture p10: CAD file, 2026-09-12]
project/mechanical/SL1-tpu.stp
90.8 x 5.00 x 91.0 mm

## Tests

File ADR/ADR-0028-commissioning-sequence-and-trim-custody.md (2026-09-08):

<!--
SPDX-FileCopyrightText: 2026 The IndustryGrow contributors
SPDX-License-Identifier: CC-BY-SA-4.0
-->

# ADR-0028: Commissioning sequence and calibration-trim custody

- **ID:** ADR-0028
- **Status:** Accepted
- **Date:** 2026-08-28
- **Project:** IndustryGrow
- **Parent:** ADR-0017 (rev 2)
- **Companions:** ADR-0007 (rev 1), ADR-0014 (rev 6), ADR-0021, ADR-0027
- **Realizes:** ADR-0027's deferred *"the provisioning tool"* and *"where the assignment is recorded against the instance"*

## Revision history

- **Amendments** — decision 10 (2026-09-03): where the corrected device holds no writable store,
  the trim lives in a module-resident EEPROM; qualifies decision 2 for that case only.

## Context and problem

ADR-0027 fixes Node-ID storage and the provisioning write, and defers the tool and the instance
record. The M01 U3 temperature offset is the first calibration trim in the project (M01
specification §10, O-45); `store/E0002-000001-M-calibration-protocol.md` fixes its determination,
its verification and the `-CP` / `-CC` records it produces.

Fixed by no document: the order of flashing, Node-ID provisioning, bring-up, calibration and
record filing; which store holds a trim; the effect on a trim of a reflash, a module swap or a
sensor replacement; and when a recorded trim may be applied without re-determination.

| # | Device property | What it excludes | Source |
|---|---|---|---|
| P1 | A trim is measurable only on an assembled board, running, at thermal equilibrium in its operating mode | Any sequence supplying a trim before the assembled board exists | Calibration protocol §4, §5 |
| P2 | The SCD41 applies its stored offset internally and derives RH from the corrected temperature | Correction downstream of the device — the offset reaches RH by a path a consumer cannot invert | SCD4x datasheet |
| P3 | The offset EEPROM is rated for at least 2000 write cycles | Unbounded write frequency | SCD4x datasheet |

## Decision drivers

- A trim describes the module. The ADR-0027 store describes the carrier (decision 3).
- Re-determination costs ≥ 12 h in an uncontrolled ambient and ≥ 1 h in a held one (calibration
  protocol §5).
- Two unprovisioned nodes collide at `127` (ADR-0027 decision 6).
- Instance data belongs to the ERP; the repository holds procedures (ADR-0017, *Registry and store
  location*; ADR-0021 decision 7).
- Subjects 4120 and 4121 are invalid until a trim is in force (M01 specification O-45).

## Decision

1. **Commissioning is an ordered sequence. Each step's precondition is the previous step's pass.**

    | # | Step | Artefact |
    |---|---|---|
    | 1 | Flash the released image over SWD | — |
    | 2 | Provision the Node-ID | ADR-0027 decision 5 |
    | 3 | Execute the bring-up protocol | instance `-QP` |
    | 4 | Execute the calibration protocol, once per trim the class declares | instance `-CP`, `-CC` |
    | 5 | File the records | ERP (ADR-0021 decision 7) |

    Steps 4 and 5 are omitted for a class that declares no trim.

    Commissioning workflow: flash, provision, bring up, then calibrate or restore

2. **A trim is held in the device whose behaviour it corrects.** The M01 U3 offset is held in the
   SCD41's EEPROM, not in the ADR-0027 carrier store, which follows the carrier and not the module
   (alternative A). Decision 10 covers a device that has no writable store.

3. **The authoritative record of a trim is the instance `-CC`** (ADR-0017 decision 11). The device
   holds a working copy. Where the two differ, the `-CC` governs and the difference is a fault,
   not a revision.

4. **No trim is written at flash time.** Flashing writes MCU flash. Trims are written over the bus,
   by command, on a running node.

5. **A device with no trim operates at its factory default and reports it.** Firmware does not
   write a default back. The boot log distinguishes the factory default from any other value and
   does not assert which run produced a value.

6. **A trim is written only when the device read-back differs from the intended value** by more
   than the device's quantisation. This bounds consumption of the P3 budget.

7. **A recorded trim may be applied without re-determination only if the instance identifier
   matches and every validity condition named in its `-CC` still holds.** Enclosure, mounting and
   any operating parameter the `-CC` names are validity conditions. A change to one voids the
   `-CC`; the trim is then re-determined, not restored.

    ADR-0017 decision 11 anticipates a validity *period*, which suits a probe that drifts on a
    schedule; a fixed offset is voided by a change to its measurement conditions instead. A `-CC`
    may state a period, a set of conditions, or both, and is void when either is exceeded.

8. **Sensor replacement voids the trim.** The replacement holds its factory default and was not
   the part measured, so decision 7's conditions cannot be met.

9. **The commissioning tool is an operator tool.** It sequences decisions 1–7 and refuses a
   restore whose conditions fail. It does not allocate identifiers (ADR-0027 decision 7) and does
   not determine trims.

10. **Where the corrected device holds no writable store, the trim lives in a module-resident
    EEPROM** *(added 2026-09-03)*.

    Decision 2 assumes the corrected device has a store. M04-PLANT is the first class where it has
    none: the MLX90640's EEPROM carries factory calibration, and the 768-entry flat field that
    corrects its ±0.5 K fixed-pattern non-uniformity has no user cell. Decision 2 is unchanged
    wherever a store exists.

    | Corrected device | Store |
    |---|---|
    | Has a writable store | That device — decision 2 |
    | Has none | A serial EEPROM **on the module**, at an address in the `0x50`–`0x57` block ADR-0014 decision 6 reserves project-wide |

    The module-resident store keeps decision 2's property: the trim travels with the module it
    describes, so alternative A's silent failure stays closed. It is not the ADR-0027 carrier store
    and does not become one.

    Bounds:

    - A module without such a store declares no trim (decision 5); this decision adds one to no
      class that does not need it.
    - Byte 0 of that EEPROM remains the class ID of ADR-0014 decision 6, read or not. Fitting one
      is within that decision, not a change to the taxonomy.
    - Decisions 3 to 9 apply unchanged — the `-CC` governs, nothing is written at flash time, and
      replacing the corrected device voids the trim.
    - The write mechanism for a trim too large for a register is downstream (ADR-0000 decision 2)
      and is fixed by the class specification, not here.

## Alternatives considered

**A. Hold trims in the ADR-0027 carrier flash store.** *Rejected:* lifecycle mismatch. That store
follows the carrier by its decision 3; a trim describes the module. The failure mode is silent —
a swapped module is corrected by another board's value rather than reporting no trim.

**B. Supply the trim at flash time from a build-time table.** *Rejected:* P1. The value does not
exist before the board is assembled and at equilibrium. It also spends a write cycle per flash,
against decision 6.

**C. Hold the trim only in the ERP and apply it at each boot.** *Rejected:* it makes published
values depend on gateway reachability at boot, and by P2 the device applies its stored offset
regardless, so the device holds a copy in any case.

**D. Correct downstream, in the gateway.** *Rejected:* P2. Correction upstream of the device's own
RH derivation is the only correction that reaches both quantities.

**E. Re-determine at every commissioning, with no restore path.** *Rejected:* it charges a full
determination to a routine reflash, and the `-CC` already carries the conditions under which a
value remains valid.

**F. For a device with no store of its own, hold the trim at the gateway and correct there.**
*(decision 10)* *Rejected:* published values would depend on which gateway the module is attached
to, and the node's own 1 Hz statistics would stay uncorrected. P2's reasoning does not apply — an
imager's field is correctable downstream — but alternative A's failure mode does: the correction
stops travelling with the module.

## Consequences

### Positive

- Commissioning has a fixed order; the tool implements it rather than defining it.
- A trim cannot be applied to a module it was not measured on.
- Flashing and Node-ID provisioning remain independent of trims.
- O-45's validity statement gains a mechanism: 4120 and 4121 become valid for an instance when its
  `-CC` is filed, and for that instance only.

### Negative

- Trim custody is split between the device and the ERP. Detecting divergence is new work, and
  decision 3 does not fix where it runs.
- *(decision 10)* A class whose device holds no store carries an EEPROM it would not otherwise
  fit, and a second store to keep consistent with its `-CC`.
- Sensor replacement costs a re-determination.
- The tool requires ERP read access at commissioning.
- A class that declares a trim cannot be commissioned by flashing alone.

## Deferred decisions

- **The tool's interface and transport.** An operational specification, as ADR-0027 left it.
- **Trim types beyond the M01 U3 offset.** Each is declared by its class specification and its
  calibration protocol.
- **Where a device-versus-record divergence is detected and reported.** Candidates are the node's
  diagnostic channel and the gateway.
- ~~**Interaction with the firmware update path.**~~ — discharged 2026-08-29 by ADR-0029:
  ADR-0027 decision 4 is a named constraint there (property P3), and decision 1's partition
  table puts sector 11 outside both application slots.

## References

- ADR-0007 (rev 1): PKI and secure element identity — the ATECC608's scope.
- ADR-0014 (rev 6): Sensor node taxonomy — the class ID and its transports.
- ADR-0017 (rev 2): Component, document and instance identification — decision 11 fixes `-CP` and
  `-CC`; the *Registry and store location* section keeps instance data out of the repository.
- ADR-0021: Instance and integration ERP — decision 7 fixes the lifecycle-document index.
- ADR-0027: Node identity model — decisions 3, 4, 5, 6 and 7, and the deferred items this ADR
  realizes.
- `store/E0002-000001-M-calibration-protocol.md`: the M01 U3 offset procedure and its records.
- `spec/E0002-R-specification.md`: §10 and O-45.
- `spec/E0005-R-specification.md`: the flat-field trim of decision 10, its store, and its open
  determination protocol (O-99).

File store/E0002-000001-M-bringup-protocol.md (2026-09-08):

<!--
SPDX-FileCopyrightText: 2026 The IndustryGrow contributors
SPDX-License-Identifier: CC-BY-SA-4.0
-->

# M01-CLIMATE bring-up protocol — `E0002-000001-M-bringup-protocol`

- **Type:** Manual, document layer **M** (ADR-0017 d9).
- **Subject:** the design `E0002-000001` (M01-CLIMATE), on an `E0001` carrier.
- **Scope:** type-level. One execution against one instance produces that instance's `-QP`
  (ADR-0017 d10): serials, ATECC608 identity, measured values.
- **Results:** to the ERP lifecycle index as `Exxxx-VVVVVV-NNNNNN-QP` (ADR-0021 d7), not this
  repo. Result columns stay blank here.

---

## 1. Prerequisites

| Item | Requirement | Source |
|---|---|---|
| Board under test | One `E0002-000001`, assembled | — |
| Carrier | One `E0001` instance with a WeAct STM32F405RGT6 core board | ADR-0002 rev 3 |
| Gateway | `SP0004` on `can0` at 500 kbit/s, terminated | `SP0004-M-gateway-bringup` |
| Supply | `+12 V` SELV | ADR-0018 |
| Programmer | ST-Link V3 over SWD | — |
| Firmware | `store/E0001-000001-F-boot.hex` and `-F-slot-a.hex` — the bootloader and one application image; the application holds every personality and the module-ID strap selects M01 at runtime | ADR-0017 d16, ADR-0029 d1 |
| Addresses | `spec/E0002-R-specification.md` §4. All three devices sit at their part-default addresses; `E0002` has no pin map of its own | — |

**Bench gotchas.** Four, each of which has cost time before:

1. The ST-Link asserts NRST. Unplug it for any soak run, or the board resets under you.
2. **The debug console survives the whole run.** Unlike M05, M01 claims no header GPIO
   (spec §5), so USART1 (PA9/PA10, 115200 8N1, via the ST-Link VCP) is a console through boot
   *and* operation. The M05 habit of printing everything before `sensors_init()` does not apply.
3. `VCC` on the STDC14 header is sense-only. Power the board from the supply, not the probe.
4. Drop SWD to `freq=950` for anything that reads flash. At higher rates `--upload` and `-v`
   fail on a good flash, so a verify failure there is the link, not the image.

---

## 2. Flash and boot

```
STM32_Programmer_CLI.exe -c port=SWD mode=UR freq=950 -d store/E0001-000001-F-boot.hex -v
STM32_Programmer_CLI.exe -c port=SWD mode=UR freq=950 -d store/E0001-000001-F-slot-a.hex -v
```

Two images, because the bootloader and the application occupy separate sectors (ADR-0029 d1).
Each carries its own load address, so neither needs one on the command line, and neither reaches
the Node-ID sector.

| # | Step | Pass criterion | Result |
|---|---|---|---|
| 1 | SWD connect | Core ID read; VTREF reports the board's rail | |
| 2 | Flash write and verify | Verify reports no mismatch | |
| 3 | Boot to application | Application runs, no fault loop | |
| 4 | Strap decode | Boot log reads `module-id strap = 0b001 -> M01-CLIMATE (E0002)` | |

A strap that decodes to anything else is a carrier or header fault, not a module fault. The
personality is selected at runtime; no M01-specific image exists to reflash.

---

## 3. bxCAN and Cyphal bring-up

| # | Check | Pass criterion | Result |
|---|---|---|---|
| 5 | CAN loopback self-test | Boot log reports it passed | |
| 6 | Bit rate | 500 kbit/s, matches the gateway | |
| 7 | Bus errors | Zero over the run | |
| 8 | Heartbeat, subject 7509 | Present and periodic | |
| 9 | Node-ID | 97 | |
| 10 | Reset cause | Heartbeat payload decodes it | |

---

## 4. I²C sensor-presence probe

I²C1 at 100 kHz standard mode, set by the shared carrier driver.

| # | Device | Address | Pass criterion | Result |
|---|---|---|---|---|
| 11 | U1 SHT45, air temperature and humidity | `0x44` | Answers, and its serial read passes CRC | |
| 12 | U2 BME68x, pressure and gas | `0x76` | Answers; variant reads **BME688** | |
| 13 | U3 SCD41, CO₂ | `0x62` | Answers; serial read passes CRC | |

**An address ACK is not a pass.** Two failure modes defeat a bare probe:

- M05's INA226 also answers at `0x44`, so an ACK there does not prove an SHT45 is fitted. The
  CRC-checked serial read is the discriminator.
- A latched I²C fault makes *every* device answer while no transfer completes (spec O-37).
  A device counts as present only once step 14 has published a sample from it.

Confirm U2's variant. `BME680` in the boot log means the §4.2 alternative was fitted; the driver
handles both, the BOM does not.

---

## 5. Functional run against bench stimuli

Ten published subjects, nine of them at 1 Hz or the U3 interval; 4117 arrives at the gas-scan
interval of spec §6.4. Expected operating ranges are in `spec/E0002-R-specification.md` §3;
a reading is a pass when it falls in the expected range for the stimulus applied.

| # | Subject | ID | Stimulus | Pass criterion | Result |
|---|---|---|---|---|---|
| 14 | Air temperature, U1 | 4112 | Ambient bench air | In the spec §3 expected range; tracks a reference thermometer in the same air | |
| 15 | Air humidity, U1 | 4113 | Ambient bench air | In the spec §3 expected range | |
| 16 | VPD | 4114 | Derived on-node from U1 alone | Consistent with 4112 and 4113 per spec §6.1 | |
| 17 | CO₂ | 4115 | Ambient bench air, then exhaled breath at the sensor | Ambient in range; breath drives it up and it recovers | |
| 18 | Barometric pressure | 4116 | Ambient | Within 10 hPa of the local station reading | |
| 19 | Gas resistance sweep | 4117 | Ambient; the four setpoints of spec §6.4 | Setpoints return exactly as configured, resistances non-zero and **falling monotonically as the setpoint rises**, `valid` set. Arrives at the scan interval the boot line reports (10 s), not at the 1 s tick — allow a full interval before calling it absent. A build with `M01_GAS_SCAN` = 0 withholds it entirely and says `gas scan PARKED` | |
| 20 | Air temperature, U2 | 4118 | Ambient bench air | **Record the offset from 4112; there is no acceptance limit.** §8 budgets bias at U1 (T2, ≤ 0.1 K), not U2's own reading, and §4 makes U2's T/RH secondary and unbudgeted. The offset is a property of the gas-scan configuration in use — it was +0.03 K with the hotplate parked and +1.42 K with the four-point sweep — so it is recorded against that configuration or it means nothing | |
| 21 | Air humidity, U2 | 4119 | Ambient bench air | Consistent with 4113 | |
| 22 | Air temperature, U3 | 4120 | Ambient bench air | **Record the offset from 4112; there is no acceptance limit** — same reason as step 20, and U3 additionally carries the uncalibrated device offset of §10 until V7 runs (O-45) | |
| 23 | Air humidity, U3 | 4121 | Ambient bench air | Consistent with 4113, offset uncalibrated | |

Publication rates: 1 Hz for U1 and U2; U3 publishes one sample per 5 s interval, which is the
only interval the device offers.

### 5.1 U3 configuration state — what to confirm

The boot log reports what the configuration did about automatic self-calibration. Record it.

| Log text | Meaning |
|---|---|
| `ASC already off (no EEPROM write)` | Expected on a device this firmware has configured before |
| `ASC was ON -> off, persisted (one EEPROM cycle)` | Expected on first boot of a new device |
| `ASC was ON -> off in RAM only, NOT persisted` | The setting will not survive a power cycle |

ASC found on again after this firmware has already configured the device means the persist is
not sticking — one of the EEPROM's 2000 cycles per boot. Treat it as a defect, not a residual.

ASC is disabled by design (spec §6.3), which makes FRC mandatory. FRC is barred until five days
after the parts were soldered, must run at the 2.8 V application rail, and needs ≥ 3 min of
normal operation first. It has no entry point in the firmware — spec O-5. It is **not** part of
this protocol.

### 5.2 U3 temperature offset

The boot log reports the offset held in the device. `4.000 °C` is the device default and is not
this board's value: until V7 determines one, U3's temperature and humidity carry an
uncalibrated bias (spec O-45). Record the value; do not write one here.

### 5.3 What this protocol does not verify

No reference instrument beyond a thermometer in the same air. The functional run is a population
and publication check against plausible ambient values. U1 and U3 accuracy are the subjects of
V4 and V7, and CO₂ against a reference is V5, blocked on M07 (spec O-7).

---

## 6. Known residuals

Carry these into the instance `-QP` rather than re-deriving them. None blocks a functional pass.

| Item | Detail |
|---|---|
| Node draw unmeasured | Draw on `+12 V`, average and during a U3 burst, needs a meter in the feed. Spec O-35, V3 |
| U3 offset uncalibrated | Device holds the default; U3 T/RH carry a bias. Spec O-45, V7 |
| Boot probe cannot separate absence from fault | *Not fitted*, *failed*, *unpowered* and a latched bus fault are one observation. Spec O-37 |
| Rail ripple unmeasured | The 30 mV limit of spec §7.4.1 needs instrumentation the project does not have. Spec O-44 |
| Footprints never checked against parts | V6, never executed; the board was fabricated ahead of it |
| C8 effective capacitance not read from the DC-bias curve | V8, never executed |

Verification items V1 to V8 of the specification are **not** part of this protocol; none of them
is discharged by executing it. See `spec/E0002-R-specification.md` §11.

---

## 7. Closing the protocol

1. Record every result column against the instance, not against this document.
2. File the completed protocol as `E0002-000001-NNNNNN-QP` through the ERP
   (`POST /instances/{instance_id}/documents`, `doc_type=QP`). The blob goes to the warehouse;
   the ERP holds the metadata and the object key (ADR-0021 d7).
3. Serials are **server-issued** — allocate through the ERP (`POST /instances`), never by hand
   (ADR-0021 d4, ADR-0022 d4).
4. Acceptance is not part of this protocol. It belongs to the instance's `-QR` (ADR-0017 d10).

---

## 8. References

| Reference | Subject |
|---|---|
| ADR-0017 d9 | Document layers, `M` = Manual |
| ADR-0017 d10 | `-QP` / `-QR` definition |
| ADR-0017 d16 | One image, personality selected by the module-ID strap |
| ADR-0017, *Registry and store location* | The instance layer lives platform-side, off this repo |
| ADR-0021 d4, d7 | ERP as serial authority; lifecycle-document index over the warehouse |
| ADR-0014 | Sensor-node taxonomy, module-ID strap, presence probing |
| `spec/E0002-R-specification.md` | Module specification — expected ranges (§3), published subjects (§10.1), verification (§11), bring-up record (§11.2) |
| `store/E0001-000003-D-pinmap.md` | Carrier side of the header contract |
| `store/E0006-000001-M-bringup-protocol.md` | The same protocol for M05 |
| `store/SP0004-M-gateway-bringup.md` | The gateway side of the bench setup |

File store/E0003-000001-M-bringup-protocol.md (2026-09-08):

<!--
SPDX-FileCopyrightText: 2026 The IndustryGrow contributors
SPDX-License-Identifier: CC-BY-SA-4.0
-->

# M02-LIGHT bring-up protocol — `E0003-000001-M-bringup-protocol`

- **Type:** Manual, document layer **M** (ADR-0017 d9).
- **Subject:** the design `E0003-000001` (M02-LIGHT), on an `E0001` carrier.
- **Scope:** type-level. One execution against one instance produces that instance's `-QP`
  (ADR-0017 d10): serials, ATECC608 identity, measured values.
- **Results:** to the ERP lifecycle index as `Exxxx-VVVVVV-NNNNNN-QP` (ADR-0021 d7), not this
  repo. Result columns stay blank here.

---

## 1. Prerequisites

| Item | Requirement | Source |
|---|---|---|
| Board under test | One `E0003-000001`, assembled | — |
| Carrier | One `E0001` instance with a WeAct STM32F405RGT6 core board, **STRAP_1 wired through** | ADR-0002 rev 3, gotcha 1 |
| Gateway | `SP0004` on `can0` at 500 kbit/s, terminated | `SP0004-M-gateway-bringup` |
| Supply | `+12 V` SELV | ADR-0018 |
| Programmer | ST-Link V3 over SWD | — |
| Firmware | The bootloader and one application image; the application holds every personality and the module-ID strap selects M02 at runtime | ADR-0017 d16, ADR-0029 d1 |
| Diffuser | Kimoto OptSaver L-57 over U4's aperture, fitted or not — **record which** | spec §9 M1, M2 |
| Optical stimuli | Darkness, a broadband lamp, a red LED (630–660 nm), a blue LED (450–470 nm), a mains-driven lamp and a 365 nm UV-A source | §6 |
| Addresses | `spec/E0003-R-specification.md` §4, §5.1. `E0003` has no pin map of its own | — |

**The released `E0001-000001-F-*` artifacts carry the M02 personality and are UNSIGNED.** They
flash over SWD and **no node will accept them over the bus** — that asymmetry is deliberate
(ADR-0029 d6), and it means this protocol is an SWD procedure end to end. Before any image
reaches a node over the air it has to be rebuilt signed:
`firmware/tools/release.sh --key <pem>`. Note that a signed release also rebuilds the
bootloader with the matching verification key, so the pair is flashed together or not at all.

**Bench gotchas.** Six, and the first is the one that wastes a whole session:

1. **M02 is the first class whose strap bit 1 is set.** `STRAP_1` (PA6) reaches the MCU from
   carrier revision `E0001-000003`; on `E0001-000001` and `-000002` it arrives only with the
   `J6` pad 4 → `J3` pad 15 link added by hand. Without it the strap reads `0b000`, which claims
   no personality, and the node comes up **healthy, enumerated and publishing nothing**. That
   failure looks like a dead module and is a carrier fault. Check step 6 before anything else.
2. The ST-Link asserts NRST. Unplug it for any soak run, or the board resets under you.
3. **The debug console survives the whole run.** M02 claims no header GPIO (spec §5), so USART1
   (PA9/PA10, 115200 8N1, via the ST-Link VCP) is a console through boot *and* operation, as on
   M01 and unlike M05.
4. `VCC` on the STDC14 header is sense-only. Power the board from the supply, not the probe.
5. Drop SWD to `freq=950` for anything that reads flash. At higher rates `--upload` and `-v`
   fail on a good flash, so a verify failure there is the link, not the image.
6. **The sensing face carries U3 and U4 and nothing else** (spec §9 M10). It is the optical
   aperture; do not rest the board on it, and keep fingers and flux off both windows.

---

## 2. Incoming inspection, before power

V6 has never been executed on any board in this project, and M01's `-QP` records it as a
residual because the parts arrived after fabrication. M02's two optical parts make it cheap and
consequential: neither aperture is concentric with its package, so a footprint that is right for
the pads can still be wrong for the window.

| # | Step | Pass criterion | Result |
|---|---|---|---|
| 1 | 1:1 paper printout against the physical U4 | Pads coincide; the Ø0.900 mm aperture sits **0.609 mm from the package centre** along the 3.10 mm axis, and lands where the board expects it | |
| 2 | 1:1 paper printout against the physical U3 | Pads coincide with the OLGA-6 land pattern | |
| 3 | Measure U3's photodiode-group offset from the package centre | **Recorded, not judged.** The datasheet does not dimension it (spec O-70); this measurement is what closes the item and what an enclosure window is aligned to | |

Steps 1 and 2 discharge spec **V6**. Step 3 closes **O-70**. Record the U3 offset in the `-QP`
and raise it into the specification; it is a property of the part, not of the instance.

---

## 3. Flash and boot

```
STM32_Programmer_CLI.exe -c port=SWD mode=UR freq=950 -d store/E0001-000001-F-boot.hex -v
STM32_Programmer_CLI.exe -c port=SWD mode=UR freq=950 -d store/E0001-000001-F-slot-a.hex -v
```

Two images, because the bootloader and the application occupy separate sectors (ADR-0029 d1).
Each carries its own load address, so neither needs one on the command line, and neither reaches
the Node-ID sector.

| # | Step | Pass criterion | Result |
|---|---|---|---|
| 4 | SWD connect | Core ID read; VTREF reports the board's rail | |
| 5 | Flash write and verify | Verify reports no mismatch | |
| 6 | Strap decode | Boot log reads `module-id strap = 0b010 -> M02-LIGHT (E0003)` | |
| 7 | Boot to application | Application runs, no fault loop | |

Step 6 discharges spec **V7**. `0b000` there is gotcha 1, not a module fault. Any other value is
a carrier or header fault. The personality is selected at runtime; no M02-specific image exists
to reflash.

---

## 4. bxCAN and Cyphal bring-up

| # | Check | Pass criterion | Result |
|---|---|---|---|
| 8 | CAN loopback self-test | Boot log reports it passed | |
| 9 | Bit rate | 500 kbit/s, matches the gateway | |
| 10 | Bus errors | Zero over the run | |
| 11 | Heartbeat, subject 7509 | Present and periodic | |
| 12 | Node-ID | 98 | |
| 13 | `uavcan.node.port.List`, subject 7510 | Lists 4128, 4129, 4130 and 4131 | |
| 14 | `GetInfo` name | `org.industrygrow.node.m02` | |
| 15 | Reset cause | Heartbeat payload decodes it | |

98 is this class's bring-up assignment (spec §10). 96 and 97 are taken by M05 and M01, and 1 is
the gateway's own time master — not a stray board.

---

## 5. I²C presence probe through the bus switch

I²C1 at 100 kHz standard mode, set by the shared carrier driver. **U3 and U4 are both fixed at
`0x39`** and are separated topologically by U1, so this probe has a shape no other module's has:
the switch is checked first, and each sensor is reached with exactly one channel selected
(spec §5.2).

| # | Device | Where | Pass criterion | Result |
|---|---|---|---|---|
| 16 | U1 TCA9543A | `0x70`, master segment | ACKs, and its control register reads back the value written to it | |
| 17 | U4 AS7343 | `0x39`, channel 0 | `ID` (`0x5A`) reads `0x81` | |
| 18 | U3 TSL2585 | `0x39`, channel 1 | `ID` (`0x92`) reads `0x5C`, `REV_ID` (`0x91`) reads `0x11` | |

Step 18 discharges spec **V12**.

The boot diagnostic states the population directly:
`M02 up, 1=present, bitmask U1|U4|U3 = 7` for a full board.

**An address ACK is not a pass**, and on this module the reason is sharper than elsewhere: at
`0x39` an ACK could be either sensor, reached through the wrong channel. The device-specific ID
read is the only discriminator.

**U1 powers up with both channels deselected**, so `0x39` is unreachable until firmware has
written the control register. `0x39` silent with no channel selected is a U1 fault, not two
absent sensors (spec O-65). A failure of U2's 1.8 V rail removes U4, U3 **and** U1 together, so
the board then presents as one absent device at `0x70` — *not fitted*, *failed* and *unpowered*
stay indistinguishable (spec O-37).

### 5.1 Both channels selected — the fault the topology exists to prevent

| # | Step | Pass criterion | Result |
|---|---|---|---|
| 19 | Write U1's control register to `0x03` from a bench I²C master, then address `0x39` | The bus fault is observed and recorded | |

Step 19 discharges spec **V11**. It is **not reachable through the shipped firmware**, which
selects exactly one channel and never both; it needs a bench master on the header or a temporary
build. Seeing it once deliberately is the point — an unexplained `0x39` fault in the field is
otherwise a mystery.

---

## 6. Functional run against optical stimuli

Four published subjects at 1 Hz. Expected ranges are in `spec/E0003-R-specification.md` §3; a
reading is a pass when it falls in the expected range for the stimulus applied.

| # | Subject | ID | Stimulus | Pass criterion | Result |
|---|---|---|---|---|---|
| 20 | Spectral counts | 4128 | Darkness (sensor covered) | All twelve bands and `clear` near zero; `saturation` clear | |
| 21 | Spectral counts | 4128 | Broadband lamp at working distance | Every visible band non-zero; `gain` and `integration_seconds` present in the same record | |
| 22 | Spectral counts | 4128 | A red LED, 630–660 nm, alone in darkness | **F6 (index 8, 615–665 nm) is the largest band**, F7 (index 9) carries its wing, and the blue end stays near dark | |
| 23 | Spectral counts | 4128 | A blue LED, 450–470 nm, alone in darkness | **FZ (index 2, 423–478 nm) is the largest band** and the red end stays near dark | |
| 24 | Spectral counts | 4128 | Either LED | `clear` exceeds every individual band | |
| 25 | Autorange | 4128 | Cover, then illuminate | `gain` climbs toward 2048× under cover and falls under the lamp, one step per second; the brightest band settles between 10 % and 90 % of full scale under steady light | |
| 26 | PPFD | 4129 | Any | **`valid` = false, value 0.** This is the correct result on an uncommissioned node, not a failure — the coefficients do not exist yet (§7) | |
| 27 | Flicker | 4130 | DC bench supply driving the lamp | `valid` set; `detected_100hz` and `detected_120hz` both clear | |
| 28 | Flicker | 4130 | A lamp on mains | `detected_100hz` set with `valid_100hz` on a 50 Hz supply (`detected_120hz` on 60 Hz). This is the positive control for the flicker path | |
| 29 | UV-A irradiance | 4131 | Darkness | Near zero, `valid` set | |
| 30 | UV-A irradiance | 4131 | 365 nm UV-A source | Responds; the value is **nominal**, from a typical-only responsivity (spec §6.4) | |
| 31 | UV-A irradiance | 4131 | Warm-white lamp only, no UV | Stays at dark level. This is the visible-rejection claim of spec §6.4, measured rather than assumed | |
| 32 | Bus soak | — | Normal operation, ≥ 1 h | Both sensors addressed through their own channels, zero bus errors | |

Step 32 discharges the **second half of spec V5**. The first half — SCL and SDA measured idling
at 1.8 V rather than 3.3 V, and the low level presented to the carrier against the 76 mV `R_ON`
budget — needs a scope and is not part of this protocol.

### 6.1 Vendor commands

Two, over `uavcan.node.ExecuteCommand`. Both exist because the values they report are not
derivable from the published subjects.

| Command | Reports |
|---|---|
| 1 | The gain and integration time the autorange settled on, and the brightest band as permille of full scale |
| 2 | U3's raw UV counts and the gain behind them — the figure V4 compares against dark |

### 6.2 Diffuser state

Record whether the L-57 was fitted for this run. It transmits 60 %, and that constant enters
every band (spec §9.1). Counts taken with and without it are not comparable, and the PPFD
coefficients of §7 are only valid for the optical stack they were identified through.

---

## 7. What this protocol does not verify

| Item | Why not |
|---|---|
| PPFD absolute (**V1**) | Needs a reference quantum sensor in the canopy plane at ≥ 3 output levels, per profile phase spectrum, with the diffuser and enclosure window fitted. **The project owns no quantum sensor** (spec O-52). Until it does, 4129 publishes `valid` = false |
| A 24 h photoperiod (**V2**) | One full cycle logged, no channel saturated and none below 10 % across either 30 min ramp. Hours, not minutes, and it needs the fixture |
| Per-channel spectrum (**V3**) | Each fixture channel driven alone at full output; 730 nm far-red shall register on F8. Needs a multi-channel luminaire. **This is what confirms the band map** across all twelve; steps 22–24 only rule out a gross error |
| UV absolute (**V4**) | Needs a UV-A source of known irradiance |
| Rail measurements (**V9**, **V10**) | U4's and U3's `V_DD` at the pin under load and through U2's start-up transient, against the 1.98 V absolute maximum. Needs a scope on a 1.8 V rail with 180 mV of headroom |
| Diffuser transmission (**V8**) | Band counts with and against the fitted diffuser under one fixture setting |

---

## 8. Known residuals

Carry these into the instance `-QP` rather than re-deriving them. None blocks a functional pass.

| Item | Detail |
|---|---|
| **The firmware has never met the hardware** | Written against DS001046 v6-00 and DS001043 v5-00. Four things are most likely to be wrong on first contact, in order: the `DATA_0..17` → band assignment under `auto_smux` = 3; the AS7343 register-bank exit through CFG0 (`0xBF`), used once for the `ID` probe; the TSL2585 photodiode → modulator map; and the UV scaling constants. Steps 17, 18 and 22–24 are the cheap screens for the first three |
| `AVALID` is not a freshness flag | It stays asserted, so a stalled spectral engine would republish its last set with the node reporting NOMINAL. There is no sample counter on the part. Check the **data** across V2's 24 h cycle, never the node's health — the same distinction M01 spec O-75 was learned on |
| PPFD uncommissioned | No coefficients, no reference instrument. Spec O-52, V1 |
| Node power unmeasured | Draw on `+12 V`. Spec O-59 |
| U1 has no reset line | `RESET` tied to `V_CC`; a stuck channel is recoverable only by a node power cycle. Firmware reports it rather than attempting a reset it has no line for. Spec O-65 |
| Post-excursion validity undefined | Condensation places U4 outside its 5–85 %RH non-condensing operating conditions. Spec O-57 |
| `GND` pour on `F.Cu` only | The sensor face has no plane behind it, one board thickness from the luminaire's driver. Spec O-69 |
| Deployment constants are volatile | `industryflow.greenhouse.light.ppfd_coeff` has no store behind it (ADR-0005 d7), so a commissioned node re-takes its coefficients at every restart |

Verification items **V6**, **V7**, **V11**, **V12** and the second half of **V5** are discharged
by executing this protocol; **V1**, **V2**, **V3**, **V4**, **V8**, **V9** and **V10** are not.
See `spec/E0003-R-specification.md` §11.

---

## 9. Closing the protocol

1. Record every result column against the instance, not against this document.
2. File the completed protocol as `E0003-000001-NNNNNN-QP` through the ERP
   (`POST /instances/{instance_id}/documents`, `doc_type=QP`). The blob goes to the warehouse;
   the ERP holds the metadata and the object key (ADR-0021 d7).
3. Serials are **server-issued** — allocate through the ERP (`POST /instances`), never by hand
   (ADR-0021 d4, ADR-0022 d4).
4. Acceptance is not part of this protocol. It belongs to the instance's `-QR` (ADR-0017 d10).

---

## 10. References

| Reference | Subject |
|---|---|
| ADR-0017 d9 | Document layers, `M` = Manual |
| ADR-0017 d10 | `-QP` / `-QR` definition |
| ADR-0017 d16 | One image, personality selected by the module-ID strap |
| ADR-0017, *Registry and store location* | The instance layer lives platform-side, off this repo |
| ADR-0021 d4, d7 | ERP as serial authority; lifecycle-document index over the warehouse |
| ADR-0014 rev 6 | Sensor-node taxonomy, module-ID strap, sensor complement, presence probing |
| ADR-0029 d1, d6 | Bootloader and application in separate sectors; image signing |
| `spec/E0003-R-specification.md` | Module specification — expected ranges (§3), acquisition (§6.1), PPFD (§6.2), optical requirements (§9), firmware (§10), verification (§11) |
| `store/E0001-000003-D-pinmap.md` | Carrier side of the header contract, and `STRAP_1` |
| `store/E0002-000001-M-bringup-protocol.md` | The same protocol for M01 |
| `store/E0006-000001-M-bringup-protocol.md` | The same protocol for M05 |
| `store/SP0004-M-gateway-bringup.md` | The gateway side of the bench setup |

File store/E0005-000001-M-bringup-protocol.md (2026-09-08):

<!--
SPDX-FileCopyrightText: 2026 The IndustryGrow contributors
SPDX-License-Identifier: CC-BY-SA-4.0
-->

# M04-PLANT bring-up protocol — `E0005-000001-M-bringup-protocol`

- **Type:** Manual, document layer **M** (ADR-0017 d9).
- **Subject:** the design `E0005-000001` (M04-PLANT), on an `E0001` carrier.
- **Scope:** type-level. One execution against one instance produces that instance's `-QP`
  (ADR-0017 d10): serials, device IDs, measured values.
- **Results:** to the ERP lifecycle index as `Exxxx-VVVVVV-NNNNNN-QP` (ADR-0021 d7), not this
  repo. Result columns stay blank here.
- **State:** §2 and §3 are executable against loose U1 parts; §4 needs a fabricated board, which
  O-93 and V5 block.

---

## 1. Prerequisites

| Item | Requirement | Source |
|---|---|---|
| U1 parts | `MLX90640ESF-BAA-000-TU`. `BAB` is a different assembly E-number | spec §2, §4.1, ADR-0017 rev 2 d4 |
| Footprint print | 1:1 paper plot of `industrygrow:MLX90640_TO-39-4` from `E0005-000001-D-src.zip` | spec §11 V5 |
| Metrology | Calipers to 0.02 mm | §2 |
| Jig supply | 3.3 V, ≥ 50 mA | spec §7.2 |
| Jig bus | I²C master, 2.2 kΩ pull-ups to 3.3 V, ≤ 400 kHz | spec §5.1 |
| Jig fixture | TO-39 4-lead test socket, or flying leads. A 2.54 mm breadboard does not take a Ø5.84 mm lead circle | spec §4.1 |
| Handling | Can held by the rim; aperture clear of flux and skin; part never rested aperture-down | spec §9 M3, M4 |
| Board under test | One assembled `E0005-000001` — §4 only | — |
| Carrier | One `E0001` instance with a WeAct STM32F405RGT6 core board | ADR-0002 rev 3 |
| Gateway | `SP0004` on `can0` at 500 kbit/s, terminated, time master running | `SP0004-M-gateway-bringup` |
| Supply | `+12 V` SELV, with a current readout to 1 mA | ADR-0018, spec §7.1 |
| Programmer | ST-Link V3 over SWD; console on the VCP, 115200 8N1 | — |
| Firmware | `store/E0001-000001-F-boot.hex` and `-F-slot-a.hex` — bootloader and one application image; the application holds every personality and the strap selects M04 at runtime | ADR-0017 d16, ADR-0029 d1 |
| Reference target | A matte surface filling the field at the test distance, its temperature read by a contact thermometer | §4.5 |
| Heat source | A warm object 10 K or more above the scene, hand-held | §4.5 |
| Meter | DMM at the module's 3V3 pin | spec §11 V11 |

---
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

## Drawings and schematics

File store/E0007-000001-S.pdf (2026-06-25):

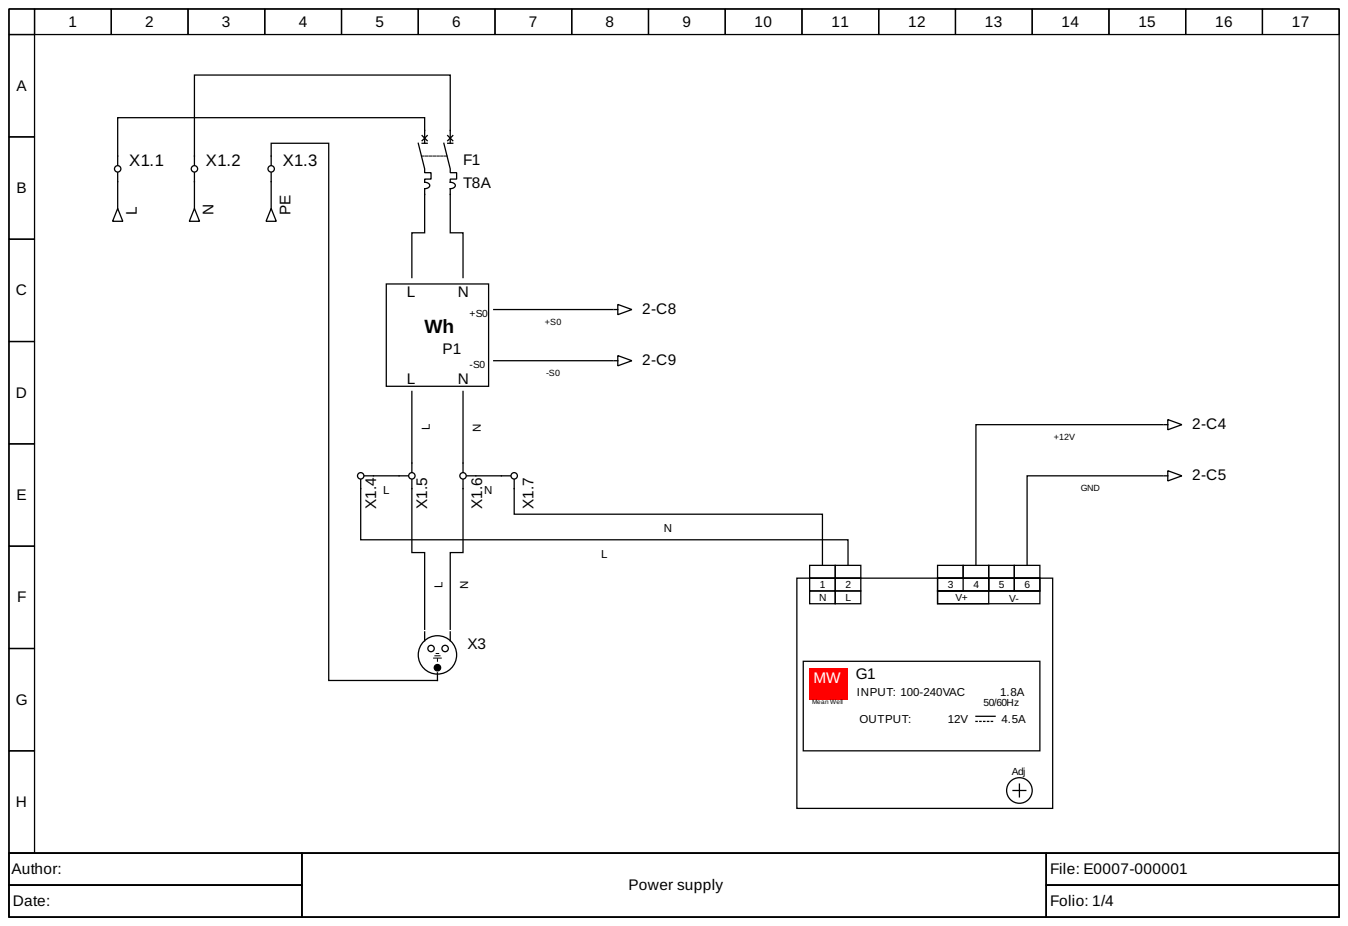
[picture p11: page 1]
Author:; Power supply; File: E0007-000001; Date:; Folio: 1/4; OUTPUT:; X DeINvPicUeT:s100-240VAC; Adj; Mean Well; GND

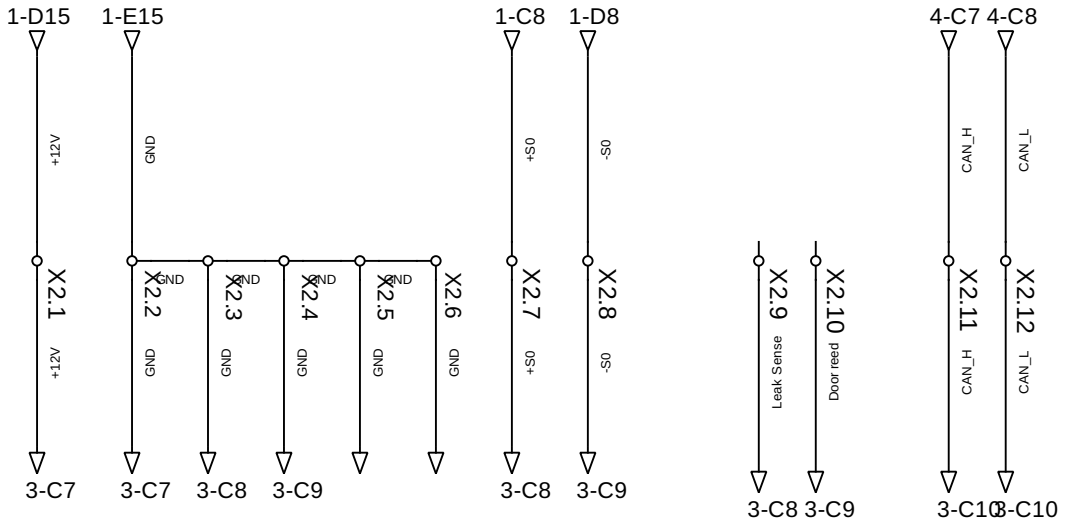
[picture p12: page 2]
Author:; Termination block; File: E0007-000001; GND; CAN_H; Leak Sense; CAN_L; GND GND; Door reed

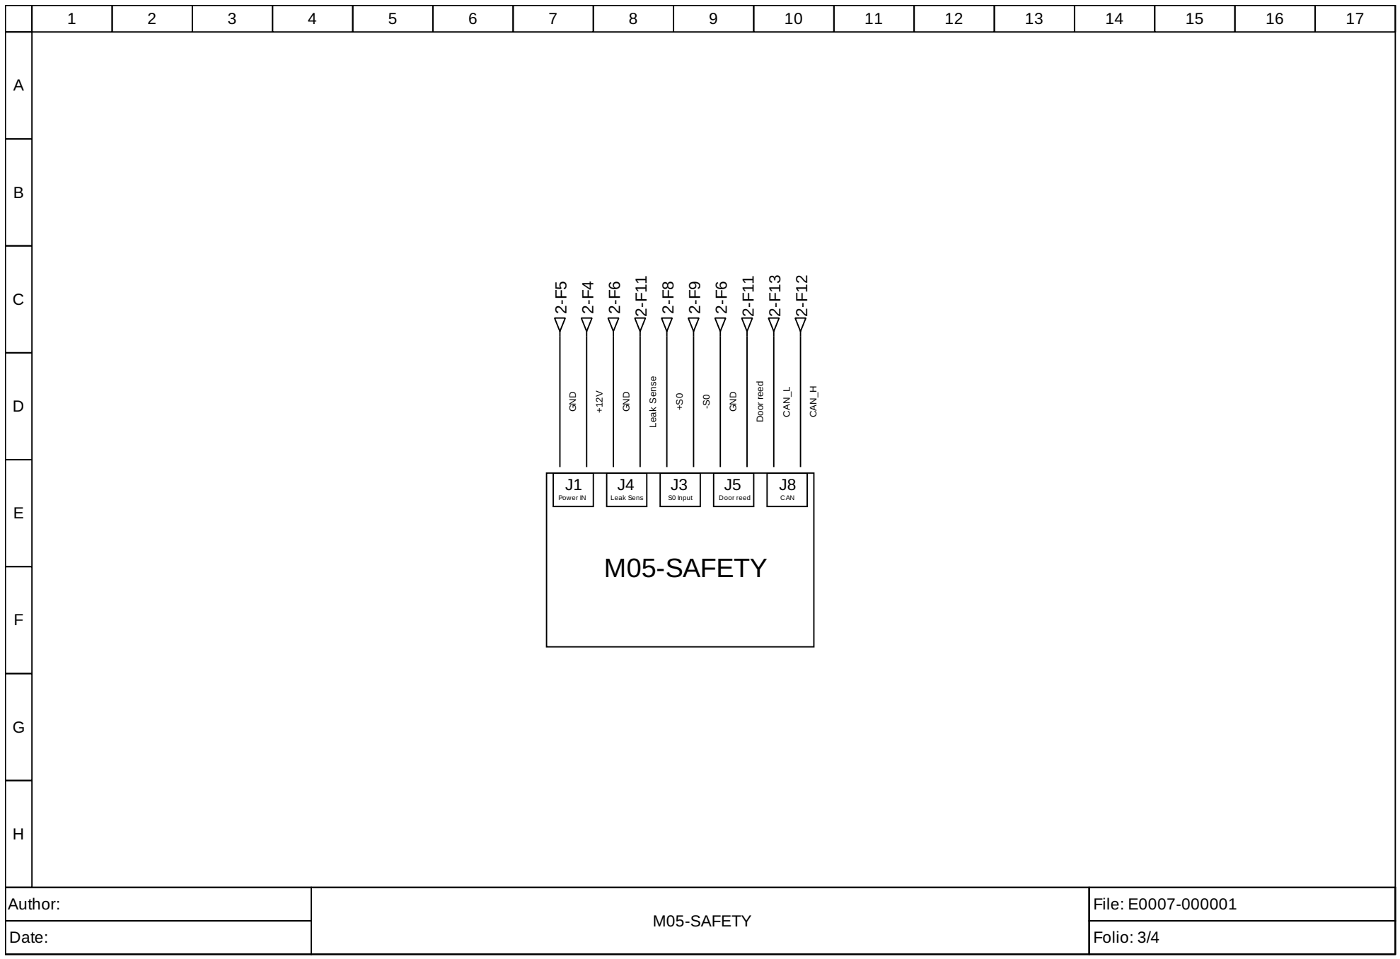
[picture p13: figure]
Author:; M05-SAFETY; File: E0007-000001; Power IN; Leak Sens; S0 Input; Door reed; CAN; GND; Leak Sense; CAN_L; CAN_H

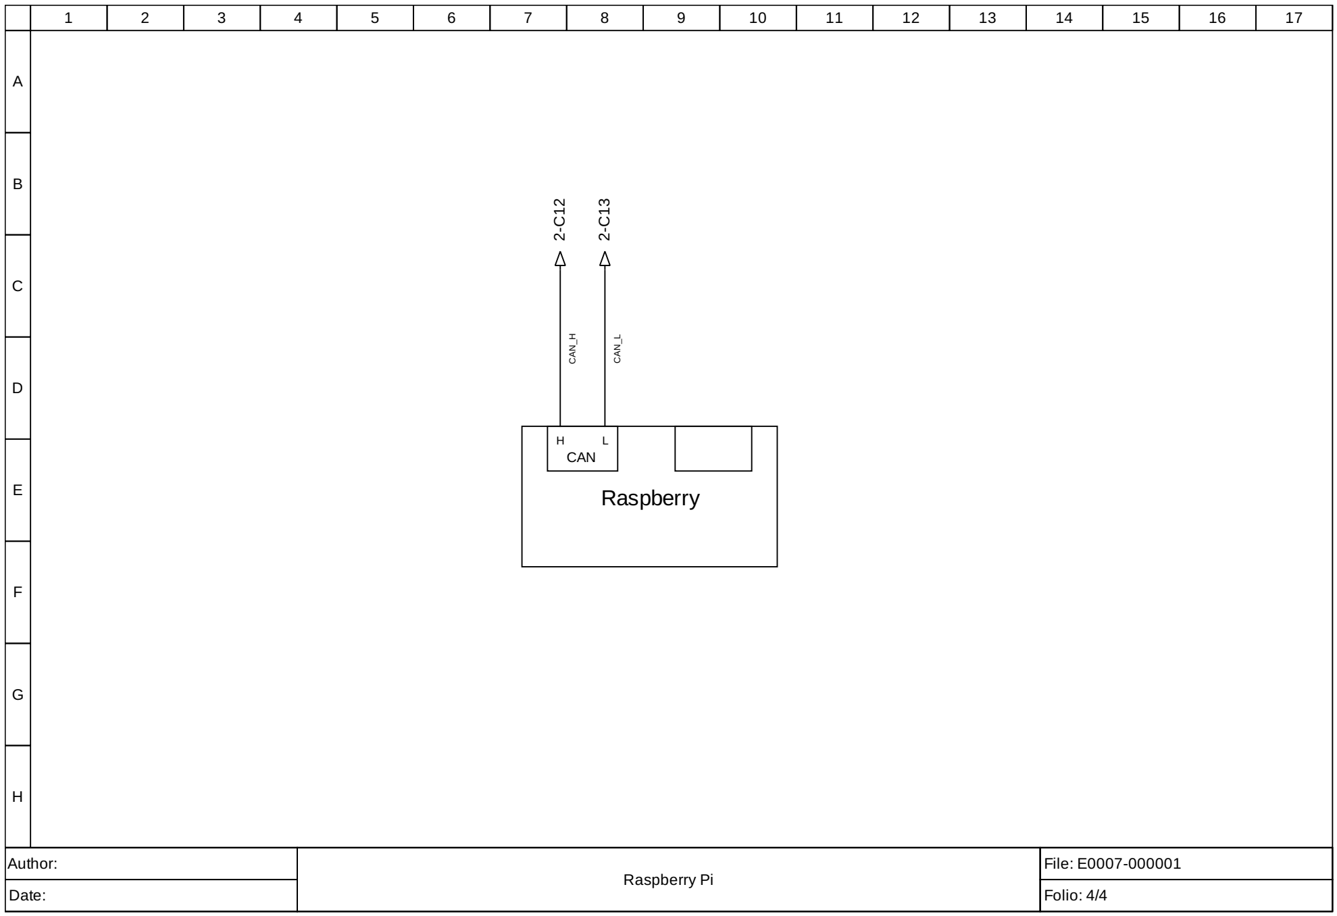
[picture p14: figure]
Author:; Raspberry Pi; File: E0007-000001; 2-C13 Raspberry; CAN; CAN_H; CAN_L

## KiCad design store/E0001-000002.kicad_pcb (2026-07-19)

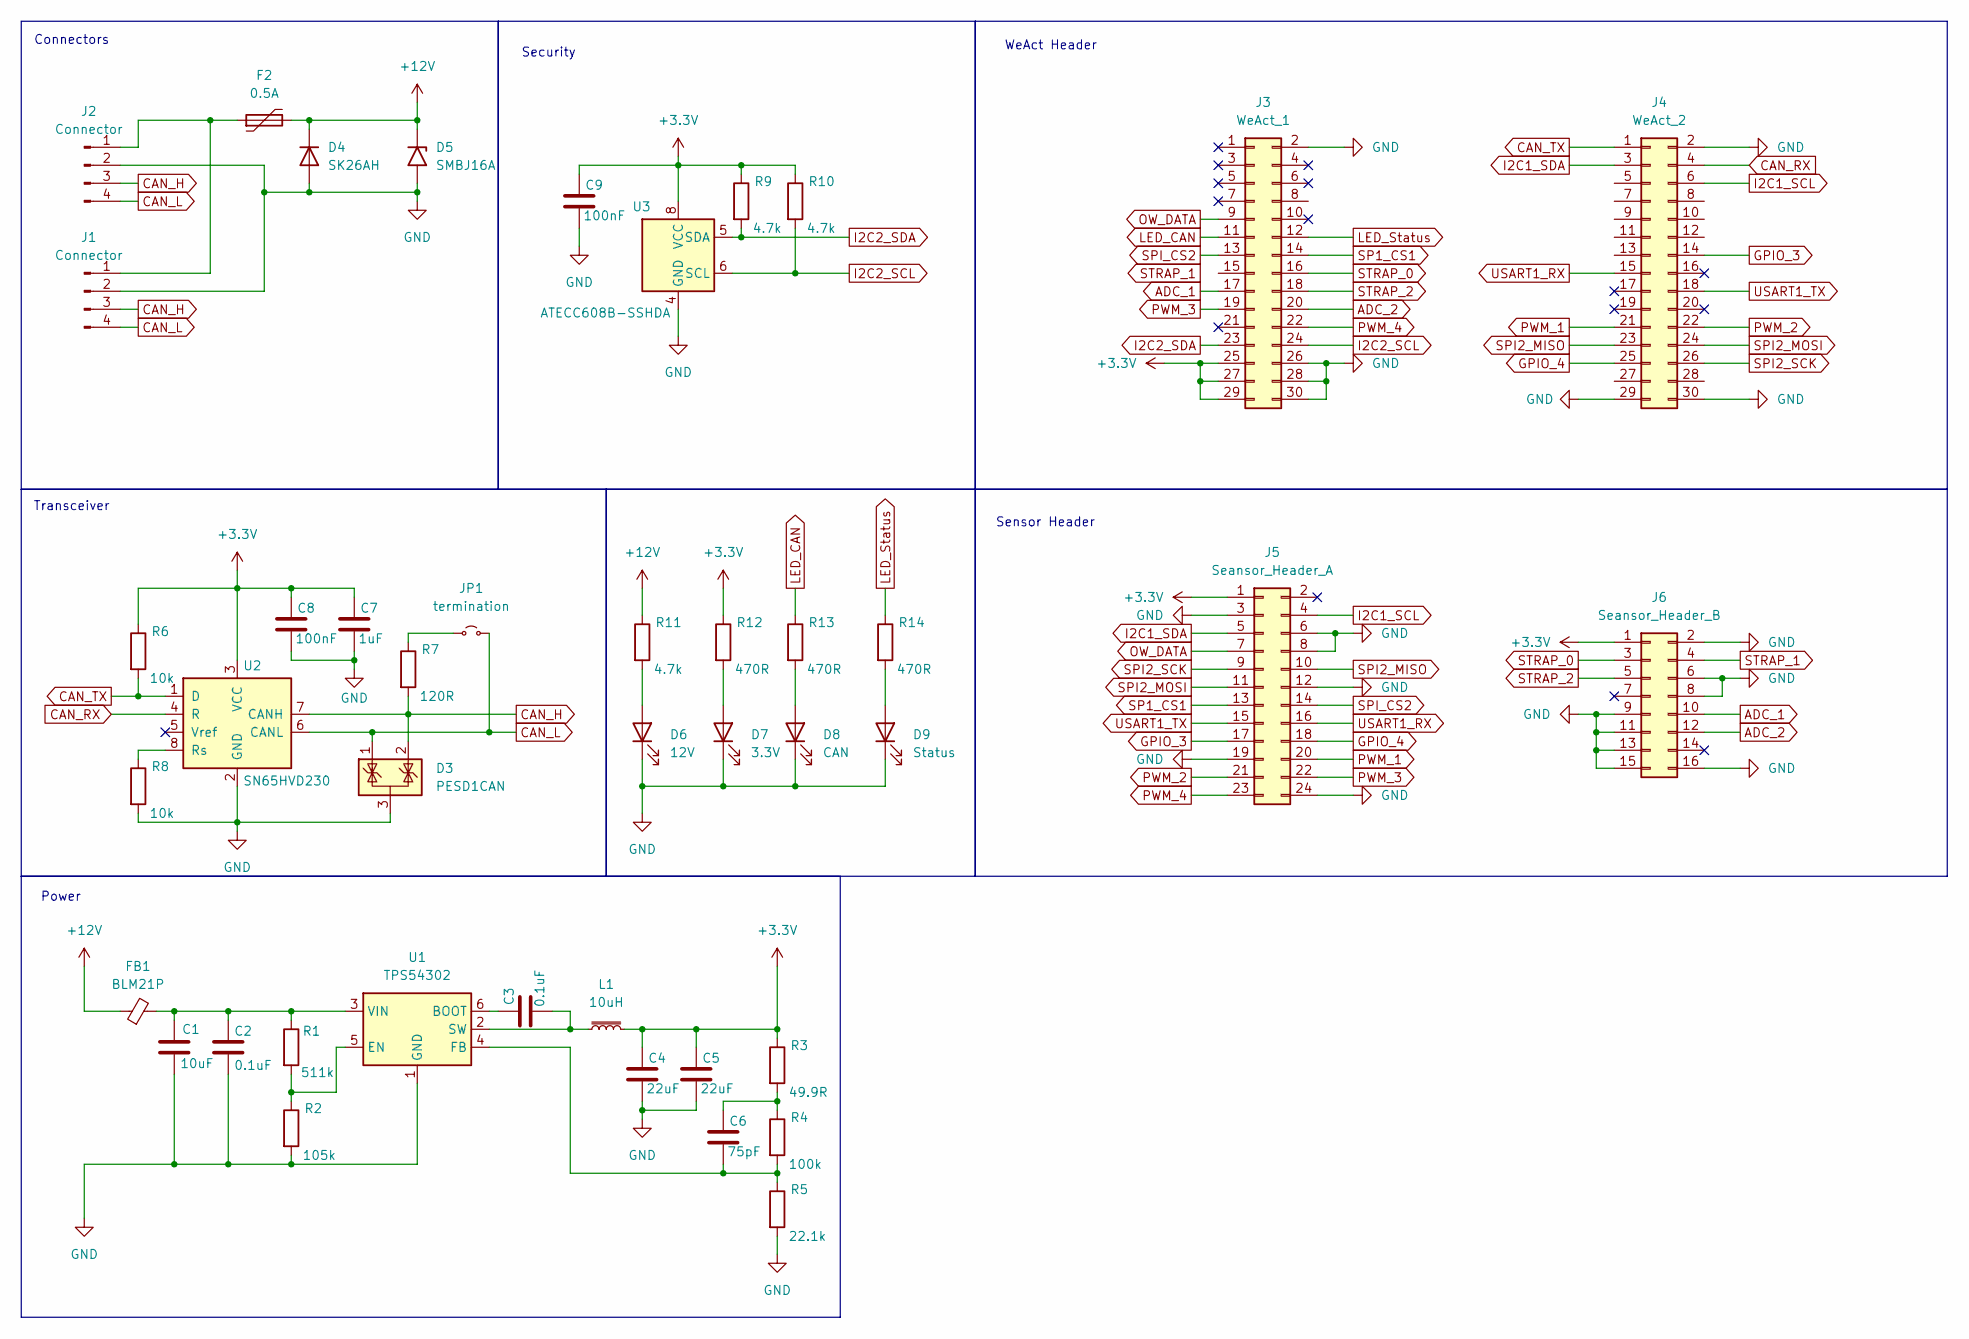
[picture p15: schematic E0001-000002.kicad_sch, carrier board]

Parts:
C1: 10uF; C_0805_2012Metric
C2, C3: 0.1uF; C_0805_2012Metric
C4, C5: 22uF; C_0805_2012Metric
C6: 75pF; C_0805_2012Metric
C7: 1uF; C_0805_2012Metric
C8, C9: 100nF; C_0805_2012Metric
D3: PESD1CAN; SOT-23
D4: SK26AH; D_SMA
D5: SMBJ16A; D_SMB
D6: 12V; LED_0805_2012Metric
D7: 3.3V; LED_0805_2012Metric
D8: CAN; LED_0805_2012Metric
D9: Status; LED_0805_2012Metric
F2: 0.5A; Fuse_0805_2012Metric
FB1: BLM21P; Fuse_0805_2012Metric
J1, J2: Connector; Molex_Micro-Fit_3.0_43045-0400_2x02_P3.00mm_Horizontal
J3: WeAct_1; PinSocket_2x15_P2.54mm_Vertical_SMD
J4: WeAct_2; PinSocket_2x15_P2.54mm_Vertical_SMD
J5: Seansor_Header_A; PinSocket_2x12_P2.54mm_Vertical_SMD
J6: Seansor_Header_B; PinSocket_2x08_P2.54mm_Vertical_SMD
JP1: termination; SolderJumper-2_P1.3mm_Open_Pad1.0x1.5mm
L1: 10uH; L_Sunlord_SWPA6045S
R1: 511k; R_0805_2012Metric
R2: 105k; R_0805_2012Metric
R3: 49.9R; R_0805_2012Metric
R4: 100k; R_0805_2012Metric
R5: 22.1k; R_0805_2012Metric
R6, R8: 10k; R_0805_2012Metric
R7: 120R; R_0805_2012Metric
R9, R10, R11: 4.7k; R_0805_2012Metric
R12, R13, R14: 470R; R_0805_2012Metric
U1: TPS54302; SOT-23-6
U2: SN65HVD230; SOIC-8_3.9x4.9mm_P1.27mm
U3: ATECC608B-SSHDA; SOIC-8_3.9x4.9mm_P1.27mm

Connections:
+3.3V: C4.1, C5.1, C7.1, C8.1, C9.1, J3.25, J3.27, J3.29, J5.1, J6.1, L1.2, R3.1, R6.1, R9.1, R10.1, R12.1, U2.3 (VCC), U3.8 (VCC)
+12V: D4.1 (K), D5.1 (A1), F2.2, FB1.1, R11.1
ADC_1: J3.17, J6.10
ADC_2: J3.20, J6.12
CAN_H: D3.2 (K), J1.3, J2.3, R7.2, U2.7 (CANH)
CAN_L: D3.1 (K), J1.4, J2.4, JP1.2 (B), U2.6 (CANL)
CAN_RX: J4.4, U2.4 (R)
CAN_TX: J4.1, R6.2, U2.1 (D)
GND: C1.2, C2.2, C4.2, C5.2, C7.2, C8.2, C9.2, D3.3 (A), D4.2 (A), D5.2 (A2), D6.1 (K), D7.1 (K), D8.1 (K), D9.1 (K), J1.2, J2.2, J3.2, J3.26, J3.28, J3.30, J4.2, J4.29, J4.30, J5.3, J5.6, J5.8, J5.12, J5.19, J5.24, J6.2, J6.6, J6.8, J6.9, J6.11, J6.13, J6.15, J6.16, R2.2, R5.2, R8.2, U1.1 (GND), U2.2 (GND), U3.4 (GND)
GPIO_3: J4.14, J5.17
GPIO_4: J4.25, J5.18
I2C1_SCL: J4.6, J5.4
I2C1_SDA: J4.3, J5.5
I2C2_SCL: J3.24, R10.2, U3.6 (SCL)
I2C2_SDA: J3.23, R9.2, U3.5 (SDA)
LED_CAN: J3.11, R13.1
LED_Status: J3.12, R14.1
unnamed: C6.1, R3.2, R4.1
unnamed: D6.2 (A), R11.2
unnamed: D7.2 (A), R12.2
unnamed: D8.2 (A), R13.2
unnamed: D9.2 (A), R14.2
unnamed: F2.1, J1.1, J2.1
unnamed: JP1.1 (A), R7.1
unnamed: C3.1, U1.6 (BOOT)
unnamed: R1.2, R2.1, U1.5 (EN)
unnamed: C6.2, R4.2, R5.1, U1.4 (FB)
unnamed: C3.2, L1.1, U1.2 (SW)
unnamed: C1.1, C2.1, FB1.2, R1.1, U1.3 (VIN)
unnamed: R8.1, U2.8 (Rs)
OW_DATA: J3.9, J5.7
PWM_1: J4.21, J5.20
PWM_2: J4.22, J5.21
PWM_3: J3.19, J5.22
PWM_4: J3.22, J5.23
SP1_CS1: J3.14, J5.13
SPI2_MISO: J4.23, J5.10
SPI2_MOSI: J4.24, J5.11
SPI2_SCK: J4.26, J5.9
SPI_CS2: J3.13, J5.14
STRAP_0: J3.16, J6.3
STRAP_1: J6.4
STRAP_2: J3.18, J6.5
USART1_RX: J4.15, J5.16
USART1_TX: J4.18, J5.15

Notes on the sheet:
Connectors
Power
Sensor Header
Security
WeAct Header
Transceiver

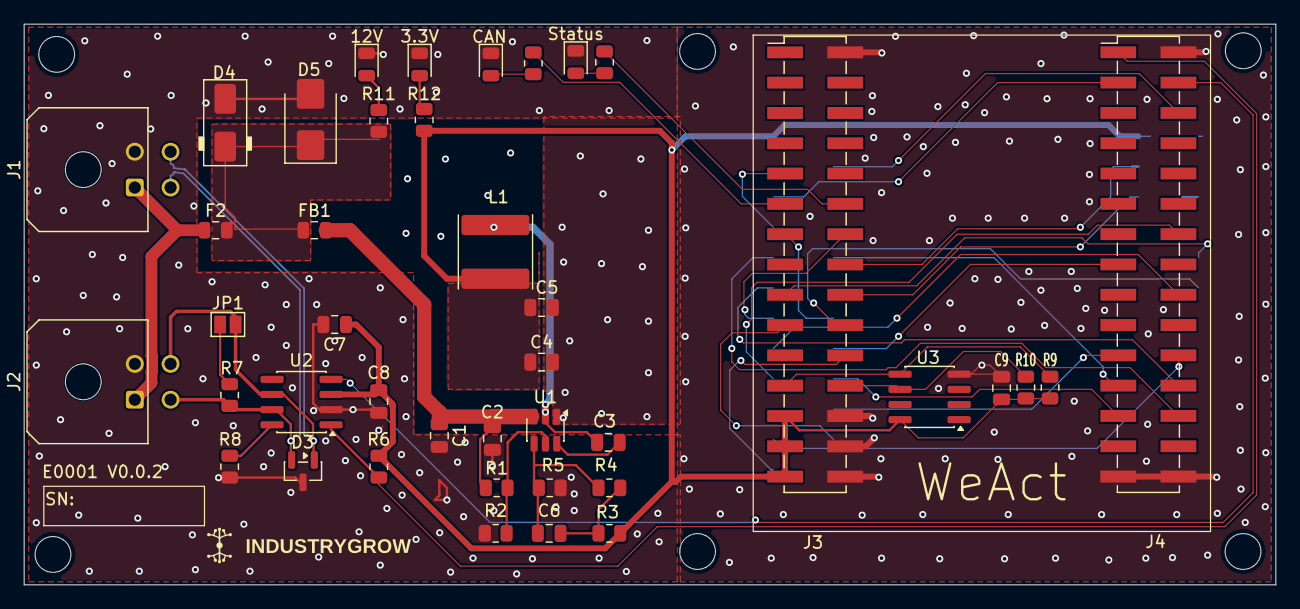
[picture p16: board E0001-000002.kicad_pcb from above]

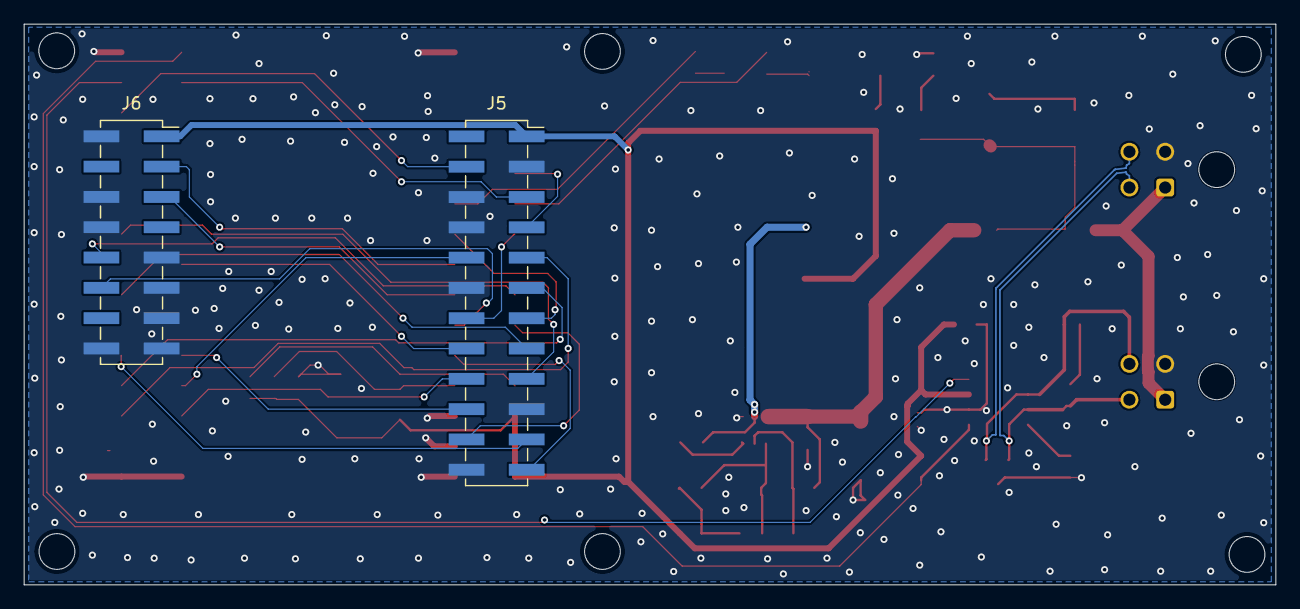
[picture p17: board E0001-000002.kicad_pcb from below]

Board: 2 copper layers, 104.9 x 47.0 mm, 44 parts (2 on the bottom side), 44 nets.

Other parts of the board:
IC1: WeAct_1; weact

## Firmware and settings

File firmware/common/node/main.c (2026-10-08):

/*
 * SPDX-FileCopyrightText: 2026 The IndustryGrow contributors
 * SPDX-License-Identifier: AGPL-3.0-or-later
 */

/*
 * IndustryGrow node firmware -- the one image every node runs.
 *
 * Boot is identical on every node: clock, carrier BSP, debug console, module-ID
 * strap read, CAN self-test, carrier identity, Cyphal node. The strap then
 * selects the sensor-module personality (ADR-0017 d16), which is the only part
 * that differs between an E0002 and an E0006 in the socket.
 *
 * Two independent questions are answered here, and neither answers the other
 * (ADR-0027 d1): the class ID says WHAT is fitted, the carrier Node-ID store says
 * WHICH INSTANCE this node is. Telemetry needs both.
 *
 * Nothing here knows what a personality measures. That is the point: a new
 * module class adds a nodes/<type>/ directory and one registry entry, and this
 * file does not change.
 */

#include "e0001.h"
#include "atecc608.h"
#include "identity.h"
#include "node.h"
#include "clock.h"
#include "partition.h"
#include "update_state.h"
#include "watchdog.h"
#include "cyphal.h"
#include "can.h"
#include "uart.h"
#if IGROW_CARRIER_000100
#include "i2c.h"
#endif

/* This image's vector table, placed first by the linker script. Its address is
 * both what VTOR must point at and how the image learns which slot it runs
 * from -- nothing else tells it. */
extern uint32_t g_pfnVectors;

/* Print a byte as two uppercase hex digits over the debug UART. */
static void put_hex8(uint8_t b)
{
    static const char hex[] = "0123456789ABCDEF";
    uart_putc(hex[b >> 4]);
    uart_putc(hex[b & 0xFu]);
}

int main(void)
{
    /* Before anything else: the image runs from a slot, not from the reset
     * vector (ADR-0029 d1), so the vector table must be pointed at this
     * image's own before any interrupt can be taken. The bootloader set it
     * already; doing it here is what makes the application correct on its own
     * terms rather than by inheritance. ST's SystemInit leaves VTOR alone. */
    SCB->VTOR = (uint32_t)&g_pfnVectors;

    /* The reset flags are sticky, so latch and clear them while they still
     * describe THIS boot rather than every boot since power-on. */
    watchdog_capture_reset_cause();

    clock_init();
    e0001_init();
    uart_init();

    uart_puts(IGROW_CARRIER_000100 ? "\r\nIndustryGrow node firmware (carrier E0001-000100) v"
                                   : "\r\nIndustryGrow node firmware (carrier E0001-000003) v");
    uart_put_u32(IGROW_IMAGE_VERSION_MAJOR);
    uart_putc('.');
    uart_put_u32(IGROW_IMAGE_VERSION_MINOR);
    /* Which slot the image is running from. An operator reading a boot log
     * through an update needs it, and it is read from the vector table
     * rather than from a build-time constant so that it reports where the
     * code actually is. */
    igrow_slot_t slot;
    if (partition_slot_of((uint32_t)&g_pfnVectors, &slot)) {
        uart_puts(", slot ");
        uart_puts(partition_slot_str(slot));
    }
    uart_puts("\r\n");
    uart_puts("last reset: ");
    uart_puts(watchdog_reset_cause_str());
    uart_puts("\r\n");

    /* The A/B boot state. Read before the bus comes up, because an update
     * request arriving over ExecuteCommand is recorded into it (ADR-0029 d3)
     * and because a trial image confirms itself out of it further down. */
    update_state_load();

    /* Module class ID -> personality (ADR-0014 rev 4 d6, ADR-0017 d16).
     *
     * E0001-000003: the 3-bit strap, reaching classes 0x01..0x07 -- every
     * sensor class defined today. E0001-000100: the module EEPROM first, the
     * strap only when nothing answers at 0x50 (E0001 spec F2, F4). An EEPROM
     * that answers but cannot be read is unidentified, never a strap module:
     * F2 forbids reading the pins of a module that carries an EEPROM. */
#if IGROW_CARRIER_000100
    uint8_t module_id = 0x00u;
    bool eeprom_answered = false;
    i2c_init();
    const int eeprom_rc = e0001_read_class_id(&module_id, &eeprom_answered);
    if (!eeprom_answered) {
        module_id = e0001_read_module_id();
        uart_puts("module EEPROM absent; module-id strap = 0b");
        uart_put_bin3(module_id);
    } else {
        if (eeprom_rc != 0) {
            module_id = 0x00u;
        }
        uart_puts("module class ID (EEPROM 0x50) = ");
        put_hex8(module_id);
    }
#else
    uint8_t module_id = e0001_read_module_id();
    uart_puts("module-id strap = 0b");
    uart_put_bin3(module_id);
#endif
    const node_personality_t *node = node_for_module_id(module_id);
    if (node != NULL) {
        uart_puts(" -> ");
        uart_puts(node->name);
        uart_puts("\r\n");
    } else {
        uart_puts(" -> UNIDENTIFIED (no personality claims this ID)\r\n");
    }
    /* All three strap bits are read. A carrier older than E0001-000003 without
     * the hand-added STRAP_1 link reads bit 1 as the pull-down 0, so it reads
     * every bit-1 class (M02/M03/M06/M07) with that bit cleared and can select
     * only M01 (0x01) and M05 (0x05) -- see common/carrier/e0001.h. */
    e0001_led_status(node != NULL);

    /* bxCAN peripheral + 500 kbit/s bit-timing self-test (internal loopback). */
    int rc = can_selftest_loopback();
    uart_puts(rc == 0 ? "CAN loopback self-test OK\r\n"
                      : "CAN loopback self-test FAIL\r\n");

    /* Carrier identity IC: probe the ATECC608 on I2C2 (ADR-0007 identity anchor).
     * Its 9-byte serial becomes the Cyphal node unique-id; absent on a bare WeAct
     * (no carrier), in which case the STM32 factory UID is used instead. */
    atecc608_init();
    uart_puts("ATECC608 carrier ID (I2C2): ");
    if (atecc608_present()) {
        const uint8_t *sn = atecc608_serial();
        uart_puts("present, SN=");
        for (unsigned i = 0; i < ATECC608_SERIAL_LEN; i++) {
            put_hex8(sn[i]);
        }
        uart_puts(" -> node unique-id\r\n");
    } else {
        uart_puts("absent -> STM32 factory UID\r\n");
    }

    /* Instance identity: the Node-ID, read from the carrier Node-ID store --
     * flash sector or U4 (ADR-0027 d2, d11). Not derived from the class -- one
     * ID per module class collides the moment a class has two instances. */
    identity_init();
    const uint8_t node_id = identity_node_id();
    uart_puts("node identity: ");
    uart_puts(identity_state_str());
    uart_puts(", node-id ");
    uart_put_u32(node_id);
    uart_puts("\r\n");

    /* Telemetry needs a provisioned identity AND a resolved personality. An
     * unprovisioned node sits at 127 and publishes no subjects (d6); a
     * provisioned node whose class resolves to nothing keeps its own Node-ID
     * and publishes nothing either, because it does not know what it would
     * publish (d10). Both stay visible: heartbeat, GetInfo, registers. */
    const bool publish = identity_provisioned() && (node != NULL);

    /* Live bus + Cyphal node: Heartbeat at 1 Hz, GetInfo, register,
     * ExecuteCommand. Brought up in every case -- a node that is visible on
     * the gateway can be diagnosed; one that stays silent cannot. */
    const char *cyphal_name = (node != NULL) ? node->cyphal_name
                                             : IGROW_NODE_NAME_UNIDENTIFIED;
    const char *description = (node != NULL) ? node->name : "unidentified module";
    (void)can_init_normal();
    cyphal_init(node_id, cyphal_name, description);
    cyphal_report_identity(identity_provisioned(), node != NULL);
    uart_puts("cyphal up: node-id ");
    uart_put_u32(node_id);
    uart_puts("\r\n");

    /* Personality bring-up. This is the slow part of boot on some modules --
     * M01's SCD41 alone blocks 500 ms for its mandatory stop, and 800 ms more
     * on the one boot that persists ASC-off to EEPROM -- which is exactly why
     * the watchdog is not running yet. */
    if (publish) {
        node->init();
    } else {
        uart_puts("skeleton only, no sensor publications: ");
        uart_puts(identity_provisioned() ? "no personality claims this strap\r\n"
                                         : "no Node-ID provisioned\r\n");
    }

    /* Bring-up is complete: a Node-ID, a personality and a live Cyphal node.
     * That is the condition ADR-0029 d12 confirms a trial image on -- an image
     * that faults or hangs before here never reaches it, and the bootloader
     * reverts to the slot that did. Writes flash only while a trial is open. */
    if (publish && partition_slot_of((uint32_t)&g_pfnVectors, &slot) &&
        (update_state_confirm(slot) == 1)) {
        uart_puts("trial image confirmed; slot ");
        uart_puts(partition_slot_str(slot));
        uart_puts(" is now the one that boots\r\n");
    }

    /* Last: the personality bring-up, the ATECC read and the CAN self-test are
     * slow and must not race the first timeout. Once started it cannot be
     * stopped. */
    watchdog_start();

    uint32_t last = millis();
    for (;;) {
        watchdog_kick(); /* the ONLY kick: from the foreground, never an ISR */
        if (publish) {
            node->spin(); /* queue sensor telemetry ... */
        }
        cyphal_spin();    /* ... and flush TX + service RX */
        if ((millis() - last) >= 500u) {
            last = millis();
            e0001_led_status_toggle(); /* liveness blink */
        }
    }
}

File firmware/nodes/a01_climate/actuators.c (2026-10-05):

/*
 * SPDX-FileCopyrightText: 2026 The IndustryGrow contributors
 * SPDX-License-Identifier: AGPL-3.0-or-later
 */

#include "actuators.h"

#include <math.h>
#include <string.h>

#include "condition.h"
#include "ds18b20.h"
#include "pca9685.h"

#include "e0001.h"
#include "clock.h"
#include "cyphal.h"
#include "registers.h"
#include "i2c.h"
#include "onewire.h"
#include "pwm.h"
#include "uart.h"
#include "uavcan/node/Heartbeat_1_0.h"       /* Health constants */
#include "uavcan/node/ExecuteCommand_1_0.h"  /* command response status */
#include "uavcan/diagnostic/Severity_1_0.h"
#include "uavcan/si/sample/temperature/Scalar_1_0.h"
#include "industryflow/greenhouse/actuator/Demand_1_0.h"
#include "industryflow/greenhouse/actuator/ElementState_1_0.h"
#include "industryflow/greenhouse/actuator/InterlockState_1_0.h"

/* Default subject-IDs (unregulated range), A01 spec 10. Baked, as every
 * personality's are until ADR-0005 d7's registers have a store. */
#define SUBJ_TEMPERATURE 4352u /* + role: U1 WB1, U2 HX1 base, U3 coil, U4 reheater */
#define SUBJ_STATE       4356u /* + element: E1..E6 */
#define SUBJ_INTERLOCK   4362u
#define SUBJ_DEMAND      4368u /* + element: E1..E6 */

enum { E1, E2, E3, E4, E5, E6, ELEMENTS };
enum { U1, U2, U3, U4 };

/* Header PWM lines (A01 spec 5). The two enables are held static, at 0 or 1. */
#define LINE_E1_EN   1u /* PWM_1 -> U5 IN1 */
#define LINE_E3_EN   2u /* PWM_2 -> U6 IN1 */
#define LINE_E1_VREF 3u /* PWM_3 -> U5 VREF through R28/C7 */
#define LINE_E3_VREF 4u /* PWM_4 -> U6 VREF1 through R34/C16 */
#define PWM_HZ 20000u   /* 10 kOhm / 1 uF: ripple well under one IPROPI LSB */

/* U9 channels (A01 spec 5). */
#define U9_E2_FAN    0u
#define U9_E4_EN     1u
#define U9_E5_FAN    2u
#define U9_E6_VALVE  3u
#define U9_E1_PH     4u
#define U9_FW_EN_U5  5u
#define U9_FW_EN_U6  6u
#define U9_E4_VREF   7u
#define U9_CHANNELS  8u

/* Interlock lines T2_N..T5_N on GPIO_1..GPIO_4, pulled up on the module and
 * pulled low by a trip (A01 spec 5, 8). Bit n of the published masks is line n. */
static const struct {
    GPIO_TypeDef *port;
    uint8_t pin;
} TRIP_LINE[4] = {{GPIOA, 9u}, {GPIOA, 10u}, {GPIOA, 15u}, {GPIOB, 12u}};
#define TRIP_T2 0x1u
#define TRIP_T3 0x2u
#define TRIP_T4 0x4u
#define TRIP_T5 0x8u
#define TRIP_BOTH_DRIVERS (TRIP_T2 | TRIP_T3 | TRIP_T4) /* the EN_CHAIN, U5 and U6 */
#define TRIP_U6_ONLY      TRIP_T5                       /* humidity-tract airflow */

/* nFAULT, U5 and U6 wired-OR, on GPIO_5 = PA5, pulled up on the module. */
#define NFAULT_PIN 5u

/* IPROPI: I = V / (A_IPROPI * R_IPROPI). 212 uA/A (DRV8262 datasheet, 7.5) into
 * 7.87 kOhm (R29, R35) puts the 1.98 A string limit at 3.30 V. ADC1 channels 14
 * and 15 are ADC_1 and ADC_2. */
#define ADC_CH_E1 14u
#define ADC_CH_E3 15u
#define AMP_PER_VOLT (1.0f / (212.0e-6f * 7870.0f))

#define STEP_US       100000u  /* conditioning at 10 Hz */
#define STEP_S        0.1f
#define PUBLISH_US    1000000u
#define U9_CHECK_US   1000000u
#define U9_FAIL_LIMIT 3u
#define OW_MAX        8u

/* --- Commissioning constants (A01 spec F7) --------------------------------
 *
 * Node-local, set at commissioning, never carried in the profile (ADR-0015
 * d18). Each is a register with the specification's value as its default.
 * None is persistent yet: like every register but uavcan.node.id they reset to
 * these defaults at power-up (ADR-0005 d7). */

/* a01.drive -- D5 dead band, D5 dwell at zero before a reversal (s), D7 slew (1/s). */
static float s_drive[3] = {0.05f, 60.0f, 0.05f};
#define DRIVE_DEAD_BAND 0
#define DRIVE_DWELL_S   1
#define DRIVE_SLEW      2

/* a01.thermal (K, s) -- D9 full scale below, D9 zero at, D9 re-enable below,
 * D10 absolute floor, D11 coil floor, the band over which a floor derates a
 * cooling demand, and the F8 sensor-loss timeout. The band is a node design
 * value the specification does not set (verify at V-tests). */
static float s_thermal[7] = {308.15f, 318.15f, 305.15f, 276.15f, 274.15f, 1.0f, 5.0f};
#define TH_D9_FULL   0
#define TH_D9_ZERO   1
#define TH_D9_REARM  2
#define TH_D10_MIN   3
#define TH_D11_FLOOR 4
#define TH_BAND      5
#define TH_TIMEOUT_S 6

/* a01.fan -- D13: E5 minimum stable duty and start-pulse duration (s). Both are
 * SP0008's and unset (O-128); zero disables each. */
static float s_fan[2] = {0.0f, 0.0f};
#define FAN_E5_MIN   0
#define FAN_E5_PULSE 1

/* a01.valve -- D14: valve fitted (1) or not (0), pulse period (s), minimum open
 * time (s). Not fitted in the baseline population (A01 spec 3.4, O-110). */
static float s_valve[3] = {0.0f, 10.0f, 0.0f};
#define VALVE_FITTED   0
#define VALVE_PERIOD_S 1
#define VALVE_MIN_S    2

/* a01.e1.heat_ph -- the U5 PH level that heats the grow volume: 1 = PH high
 * (OUT1 -> OUT2), 0 = PH low. Set by how the E0012 string is landed on J4. */
static float s_heat_ph[1] = {1.0f};

/* a01.ow.rom -- the ROM code of U1..U4, 0 = unassigned. Four DS18B20 on one bus
 * are indistinguishable until someone who knows where each is mounted says so;
 * an unassigned role publishes nothing and counts as lost (F8). */
static uint64_t s_rom[4];

/* --- Element state ------------------------------------------------------- */

typedef struct {
    float value;          /* last demand, as received */
    float kelvin;
    uint64_t deadline_us;
    bool received;
    bool stale;
    float slewed;         /* conditioned, before the derates */
    float applied;        /* what is driven */
    uint8_t state;
    cond_reversal_t rev;
    uint8_t tid;
} element_t;

static element_t s_el[ELEMENTS];

static uint8_t s_tripped;        /* interlock lines tripped now */
static uint8_t s_latched;        /* lines tripped since reset (F5) */
static bool s_fault;             /* nFAULT seen; latched until reset (F9) */
static bool s_block_cut;         /* D9 hysteresis */
static uint64_t s_e5_pulse_until;
static uint64_t s_valve_cycle_start;
static bool s_valve_open;

static float s_u9_written[U9_CHANNELS];
static bool s_u9_force = true;   /* rewrite every channel on the next step */
static uint8_t s_u9_fails;
static bool s_u9_lost;

static uint64_t s_rom_found[OW_MAX];
static size_t s_rom_found_n;

static uint64_t s_last_step, s_last_pub, s_last_u9_check;
static uint8_t s_tid_temp[4], s_tid_interlock;
static uint8_t s_last_tripped;
static bool s_last_fault;

#define ST(name) industryflow_greenhouse_actuator_ElementState_1_0_STATE_##name

/* --- Demands -------------------------------------------------------------- */
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

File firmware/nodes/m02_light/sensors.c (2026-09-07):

/*
 * SPDX-FileCopyrightText: 2026 The IndustryGrow contributors
 * SPDX-License-Identifier: AGPL-3.0-or-later
 */

#include "sensors.h"

#include "clock.h"
#include "cyphal.h"
#include "registers.h"
#include "uart.h"
#include "i2c.h"
#include "tca9543a.h"
#include "as7343.h"
#include "tsl2585.h"

#include "uavcan/node/Heartbeat_1_0.h"      /* Health constants */
#include "uavcan/node/ExecuteCommand_1_0.h" /* command response status */
#include "uavcan/diagnostic/Severity_1_0.h"
#include "industryflow/greenhouse/light/SpectralSample_1_0.h"
#include "industryflow/greenhouse/light/PhotonFluxDensity_1_0.h"
#include "industryflow/greenhouse/light/FlickerStatus_1_0.h"
#include "industryflow/greenhouse/light/Irradiance_1_0.h"

/* Default subject-IDs, unregulated range. ADR-0005 d7 wants these register-
 * configurable (uavcan.pub.<name>.id) with these as defaults; baked for now,
 * as on M05 and M01. M05 holds 4096-4102 and M01 4112-4121, so M02 starts at
 * 4128 and leaves M01's block room to grow.
 *
 * 4132 and 4133 were UV-B and UV-C and are RETIRED, not reassigned (M02 spec
 * 10.1): ADR-0014 rev 6 withdrew the AS7331 that measured them, and a gateway
 * holding an older register set must not silently bind a new quantity to an
 * identifier it already knows as something else. Nothing here may use them. */
#define SUBJ_SPECTRUM 4128u /* U4 AS7343 -- 12 bands + clear + settings */
#define SUBJ_PPFD     4129u /* derived on-node from U4, spec 6.2 */
#define SUBJ_FLICKER  4130u /* U4 AS7343 -- ADC5 */
#define SUBJ_UV_A     4131u /* U3 TSL2585 */

#define PUBLISH_PERIOD_US 1000000u
#define REPROBE_PERIOD_US 60000000u

/* The autorange window of M02 spec 6.1: hold the brightest mapped channel
 * between 10 % and 90 % of full scale. */
#define AUTORANGE_LOW  0.10f
#define AUTORANGE_HIGH 0.90f

/* Device indices, in the order the health bitmask reports them. */
#define DEV_U4 0u /* AS7343 -- the board's purpose */
#define DEV_U3 1u /* TSL2585 -- the UV trace */
#define DEV_N  2u

#define FAIL_DEGRADED 3u

/* Vendor ExecuteCommand IDs. Both serve residuals this board actually has and
 * cannot resolve from a datasheet: the autorange has never met a luminaire,
 * and the UV responsivity is a typical with no bounds (spec 6.4, V4). */
#define CMD_SPECTRUM_STATE 1u
#define CMD_UV_RAW         2u

/* The PPFD reconstruction coefficients of M02 spec 6.2, over the ten in-window
 * bands F1 (405 nm) .. F7 (690 nm). Zero is the uncommissioned state and the
 * only honest default: the coefficients belong to one luminaire spectrum and
 * one optical stack identified against a reference quantum sensor, and the
 * project owns no such instrument (O-52). They arrive over the register below,
 * from the deployment profile -- never compiled in (spec 10). */
#define REG_PPFD_COEFF "industryflow.greenhouse.light.ppfd_coeff"
static float s_ppfd_coeff[AS7343_PAR_BANDS];

static bool s_u4, s_u3, s_switch;
static bool s_seen[DEV_N];
static uint8_t s_fail[DEV_N];

static uint8_t tid_spectrum, tid_ppfd, tid_flicker, tid_uv;
static uint64_t s_last_pub, s_last_probe;

/* The working point in force, moved by the autorange one step per publication
 * (spec 6.1). Seeded at the expected full-output point rather than at either
 * extreme: a node that comes up mid-photoperiod is then already in range. */
static uint8_t s_atime = AS7343_ATIME_NORMAL;
static uint8_t s_again = 7u; /* 64x */

static uint8_t s_last_health = uavcan_node_Health_1_0_NOMINAL;

/* The last spectral set, kept for the bench command. */
static as7343_sample_t s_last_spectrum;
static bool s_have_spectrum;

static uint64_t now_ts(void) { return micros64(); }

static void note_read(uint8_t dev, bool ok)
{
    if (ok) {
        s_fail[dev] = 0u;
    } else if (s_fail[dev] < 255u) {
        s_fail[dev]++;
    }
}

static bool coefficients_loaded(void)
{
    for (unsigned i = 0; i < AS7343_PAR_BANDS; i++) {
        if (s_ppfd_coeff[i] != 0.0f) {
            return true;
        }
    }
    return false;
}

/* U4 carries the board's purpose -- E0003 exists to measure the photic
 * environment at the canopy -- so losing it is CAUTION. U3 measures the
 * profile's UV-A trace, a secondary duty: ADVISORY.
 *
 * Losing U1 is CAUTION and not its own severity: the switch failing takes both
 * sensors with it, and the node then presents as a single absent device at
 * 0x70 rather than as two absent sensors (spec 10). The bitmask is what says
 * which of the three it was. */
static void report_health(void)
{
    const bool fault[DEV_N] = {
        (s_u4 && (s_fail[DEV_U4] >= FAIL_DEGRADED)) || (s_seen[DEV_U4] && !s_u4),
        (s_u3 && (s_fail[DEV_U3] >= FAIL_DEGRADED)) || (s_seen[DEV_U3] && !s_u3),
    };
    uint8_t health = uavcan_node_Health_1_0_NOMINAL;
    if (fault[DEV_U3]) {
        health = uavcan_node_Health_1_0_ADVISORY;
    }
    if (fault[DEV_U4] || !s_switch) {
        health = uavcan_node_Health_1_0_CAUTION;
    }
    cyphal_set_health(health);

    if (health != s_last_health) {
        s_last_health = health;
        if (health == uavcan_node_Health_1_0_NOMINAL) {
            cyphal_diagnostic(uavcan_diagnostic_Severity_1_0_NOTICE, "M02 sensors recovered");
        } else {
            cyphal_diagnostic_u32(uavcan_diagnostic_Severity_1_0_WARNING,
                                  "M02 devices lost or faulted, 1=bad, bitmask U1|U4|U3 =",
                                  (uint32_t)((s_switch ? 0u : 1u) |
                                             (fault[DEV_U4] ? 2u : 0u) |
                                             (fault[DEV_U3] ? 4u : 0u)));
        }
    }
}

/* Probe order is the topology's: the switch on the master segment first, then
 * 0x39 on each channel in turn. Probing 0x39 with no channel selected would
 * find nothing on a perfectly good board, so an absent switch short-circuits
 * to "both sensors absent" rather than to two independent absences (spec 10,
 * O-65). Each probe is backed by a device-specific read; an ACK at 0x39 is not
 * identification, and at this address it could be either sensor reached
 * through the wrong channel. */
static void probe(void)
{
    s_switch = tca9543a_present();
    if (!s_switch) {
        s_u4 = false;
        s_u3 = false;
        return;
    }

    const bool had_u4 = s_u4;
    s_u4 = (tca9543a_select(TCA9543A_CH_U4) == 0) && as7343_present();
    if (s_u4 && !had_u4) {
        if (as7343_init(s_atime, s_again) < 0) { /* configure on (re)appearance */
            s_u4 = false;
        }
    }

    const bool had_u3 = s_u3;
    s_u3 = (tca9543a_select(TCA9543A_CH_U3) == 0) && tsl2585_present();
    if (s_u3 && !had_u3) {
        if (tsl2585_init() < 0) {
            s_u3 = false;
        }
    }

    s_seen[DEV_U4] = s_seen[DEV_U4] || s_u4;
    s_seen[DEV_U3] = s_seen[DEV_U3] || s_u3;
}
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

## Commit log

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2026-07-07 fix(gateway): cap MCP2515 SPI clock for Pi 5 RX (spimaxfrequency)
    On the Pi 5 (RP1), the default MCP2515 SPI clock is too fast: the
    register reads that clear the controller INT flag get corrupted, the
    interrupt storms, and the driver never surfaces received frames — RX is
    dead while init and TX still look fine. The MCP2515 internal loopback
    exposes it (nothing loops back).
    Add IGROW_CAN_HAT_SPI_MAXFREQ (default 1000000) and emit it as
    spimaxfrequency= on both mcp2515-can* overlays; empty keeps the driver
    default for Pi 4 / older. Verified on gbox-dev (Pi 5): internal loopback
    went from dead to delivering frames after the change + reboot.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
2026-07-08 fix(gateway): correct MCP2515 HAT INT GPIOs (can0=23, can1=25)
    The provisioning defaults set the Waveshare 2-CH Isolated CAN HAT interrupt
    pins to can0=25/can1=24, but this board solders INT0 to GPIO23 and INT1 to
    GPIO25. With the wrong pins a controller never receives its interrupt: it
    initializes over SPI and TX appears fine, but no frames are delivered
    (confirmed via MCP2515 internal loopback — one channel dead, TX packets=0).
    Set the defaults to the documented mapping (can0=23, can1=25) in both
    provision.sh and gateway.env.example. Both channels now pass internal
    loopback. Also corrects the env-example note that misattributed the symptom
    to a physically dead CAN0 block.
    Signed-off-by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
2026-07-09 ADR-0021: instance-and-integration ERP; ADR-0000 rev 1 (ADR namespace)
    Add ADR-0021 (Proposed): a compact, self-hostable, containerized ERP as the
    pre-cloud system of record for the instance/integration layer ADR-0017
    deferred. It owns gboxes + instances (serials, ATECC bindings), integration
    history (the mutable cross-reference), the lifecycle-document index over the
    object store, deployment-specific profiles, and SP stock — each bounded so it
    never becomes a second source of truth. Operates single-tenant/private but
    conforms to IndustryFlow's multitenant production_unit model, so stage-11
    integration is core-plus-layer (not absorption), a migration not a rewrite.
    Amend ADR-0000 to rev 1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
2026-07-19 restore(store,adr): recover fab packages + ADR-0017/0019 dropped by history rewrite
    The main-branch rewrite that landed the ADR-0021 ERP scaffold (PRs #89/#90) was
    cut from the 2026-07-09 (#79) base and force-pushed, silently reverting work
    merged after it. This restores that collateral to the canonical local (3c8b2b5)
    form, on top of the ERP history:
    - store/: restore E0001-000002-D-fab.zip, E0006-000001-D-fab.zip,
    E0006-000001-D-pos.csv, E0006-000001-L.csv, SP0004-D-rp5-case-src.zip and the
    E0001-000002 zone-refill KiCad edits; drop the 11 loose gerbers (the unzipped
    fab package) per ADR-0017 d18.
    - ADR-0017 rev1: restore decision 18 (live fabrication package = one -D-fab.zip).
    - AD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
    [E0001-000002-D-B_Paste.gbp, E0001-000002-D-Bottom_Layer.gbl, E0001-000002-D-Bottom_Overlay.gbo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]
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2026-08-02 firmware: use E0006's real 0.1 ohm shunt, and settle the reed polarity
    Two bench-confirmed values that were carrying placeholders.
    INA226 shunt. R1 on E0006 is 0R1 (2512), wired straight across the
    INA226's Vin+/Vin- between F1 and the J2 output -- 0.1 ohm, not the
    0.010 ohm the driver assumed. With CAL written as 16777 the current
    register came out at I * 327676, so reported current and power were
    exactly 10x high. On the bench that read 217 mA / 2.63 W for a node
    actually drawing 20.9 mA / 254 mW.
    The wrong CAL also meant the current register saturated int16 at about
    100 mA of real current. Idle draw is well under that so nothing had
    clipped yet, but any real load would have silently pin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
    [sensors.c]
2026-08-02 firmware: drive the leak excitation on GPIO_1, gated (ADR-0018 d11)
    leak_sample_raw() had the excitation commented out and a TODO saying the
    drive pin was "an E0006 net not yet in the pin map". It is GPIO_1: E0006
    runs R6 (4.7k) from GPIO_1 to the electrode, with the strip as the lower
    leg to GND and R8 (1k) + C5 (100n) filtering into ADC_1. The carrier pin
    map maps GPIO_1 to PA9.
    Until now the channel worked anyway, by accident. PA9 is also USART1_TX,
    and uart_init() leaves it driven as an idle-high TX line -- which excited
    the electrode continuously. That is the exact failure ADR-0018 d11 gates
    excitation to avoid: permanent DC bias across the electrodes oxidises
    them. It was also fragile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
    [e0001.h, main.c]
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2026-08-02 firmware: independent watchdog, and report why the node last reset
    There was no watchdog of any kind, and no fault handling: a hung node
    simply went silent until someone power-cycled it. Adds the IWDG as shared
    platform code, so every node personality gets it, not just M05.
    IWDG rather than WWDG: it is clocked by the LSI, so it still fires when
    the main clock is the thing that failed -- a WWDG on the APB bus would
    not. It is started only after init, since I2C probing, the ATECC read and
    the CAN self-test are slow and must not race the first timeout, and it is
    kicked from exactly one place in the foreground loop. Kicking from an ISR
    would keep a dead foreground alive and defeat the whole mec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
    [main.c]
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2026-08-05 M01: capture E0002-000001 schematic; spec to schematic-captured
    Schematic sources for E0002-000001 (M01-CLIMATE). Layout is empty; the
    board is not laid out and not fabricated.
    Specification moves from pre-schematic to schematic-captured: parts fixed
    to ordering part numbers, module-local 1.8 V and 2.8 V rails specified,
    component values determined. O-3, O-34 and O-41 close; O-42 to O-50 open.
    Review fixes in this commit:
    - U3/U4 renumbered in the schematic. Capture had U3 = TLV70018 and
    U4 = SCD41, inverting the spec's U1-U3 sensors / U4-U5 support-part
    grouping and contradicting every U3 reference in the spec (boot probe
    0x62, T3/T4, section 7.5, V5/V7, O-44 to O-47).
    - Section 7.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
    [E0002-000001.kicad_pcb, E0002-000001.kicad_sch]
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2026-08-08 M01: lay out E0002-000001
    Two-layer 1.6 mm board, 104.9 x 47.0 mm outline, two 3.0 mm mounting
    holes, three internal cutouts. 19 footprints, 198 track segments,
    72 vias, 9 copper zones.
    DRC is not clean: 4 errors and 1 unconnected item remain.
    - U5 (NCP114, XDFN4 1.0x1.0) pad-to-pad gap 0.132 mm against the
    0.200 mm netclass clearance; three instances
    - via inside the U1 keepout area
    - two STRAP_1 track stubs not joined
    No GND net exists in the netlist: the ground plane resolves to
    STRAP_1 (168 pads) and the rail to STRAP_0 (70 pads), and the U5
    output and enable rails are unlabelled.
    [E0002-000001.kicad_pcb]
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2026-08-08 Revert "M01: name the E0002 power nets GND and +3.3V"
    This reverts f28e02d. The STRAP_x labels are back on the schematic and the
    PCB nets are STRAP_1 and STRAP_0 again, at the same 168 and 70 references.
    Also stores the DRC exclusion in the [key, comment] form KiCad itself
    writes, replacing the bare string.
    [E0002-000001.kicad_pcb, E0002-000001.kicad_sch]
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2026-08-08 M01: add the E0002 silkscreen logo and E-number
    Copies the LOGO footprint and the E-number / SN text from E0006-000001, in
    the arrangement that board uses: version and SN above the mark.
    E0001 and E0006 carry all their parts on F.Cu and put the silkscreen on
    F.SilkS. E0002 is the other way up - 17 of its 19 footprints are on B.Cu and
    the front holds only J6 and J7 - so the block goes on B.SilkS, keeping it on
    the component side. The footprint geometry is mirrored and the text carries
    the mirror justify, so both read correctly on the back.
    Placed at 118,95, in the clear area between the J6 column and the U3 group.
    DRC unchanged at 0 violations and 0 unconnected, with no silk_over_copper,
    si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
    [E0002-000001.kicad_pcb]
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2026-08-09 M01: store the E0002 v0.0.1 fabrication package and its loose faces
    Canonicalize the KiCad Fabrication Toolkit output into store keys per
    ADR-0017 d18:
    - `E0002-000001-D-fab.zip` — 13 members (F/B copper, silkscreen, mask,
    paste; Edge_Cuts; PTH/NPTH drills + drill maps), already named on the
    KiCad layer vocabulary by the generator.
    - `E0002-000001-D-pos.csv` — CPL, 19 placements (J6/J7 Top, rest Bottom).
    - `E0002-000001-L.csv` — BOM, 11 lines. LCSC column empty pending the
    JLCPCB order sheet; the schematic carries no LCSC fields.
    The PCBWay-format export and the toolkit's `netlist.ipc` /
    `designators.csv` are not store faces and are dropped.
    REGISTRY.md: fabrication-package ta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
    [E0002-000001-L.csv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]
2026-08-09 M01: fill the E0002 BOM LCSC column from the order
    All 11 lines carry a JLCPCB part number. C8 is C1779 — the part V8
    (DC-bias curve, 2.0-4.7 uF effective at 2.8 V) resolves against.
    [E0002-000001-L.csv]
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2026-08-18 store: add the E0003 M02-LIGHT schematic and the AS7331 library
    E0003-000001 schematic only, no layout: U1 AS7343 on a module-local 1.8 V rail
    (U3), U2 AS7331 with its 3.3 M REXT reference, I2C pull-ups, module-ID straps
    0b010 through 0 R links.
    AS7331 symbol, footprint and STEP from SnapEDA: pads given a solder-mask layer
    in place of 16 unfilled mask polygons, stacked VSSA pins un-hidden. Annotated
    SnapEDA / LicenseRef-SnapEDA-unstated, overriding the store/** default.
    ERC: 16 isolated_pin_label, 5 power_pin_not_driven.
    [E0003-000001.kicad_sch]
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2026-08-18 store: supersede carrier v0.0.2 with E0001-000003
    E0001-000003: full nine-face set reissued, PA6 routed to STRAP_1, zones refilled.
    E0001-000002: nine faces archived SUPERSEDED, loose objects removed.
    REGISTRY.md: fab-package row and strap-transport note moved to v0.0.3; superseded
    row added.
    Pin-map references retargeted in 4 specs, firmware/README.md and
    E0006-000001-D-pinmap.md.
    [E0001-000003-L.csv, E0001-000003.kicad_pcb, E0001-000003.kicad_sch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]
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2026-08-20 firmware: clear the STRAP_1-unrouted flags in the carrier unit
    E0001_STRAP1_UNROUTED -> 0u and E0001_MODULE_ID_READABLE_MASK -> 0x7u in
    common/carrier/e0001.h: PA6 reaches the MCU from carrier E0001-000003, and
    E0001-000002 boards carry the J6.4 -> J3.15 link by hand.
    Strap notes in e0001.c, common/node/main.c, both nodes' module_id.h and
    firmware/README.md now state that bodge condition instead of an open gap.
    store/E0001-000001-F-src.zip re-snapshotted; -F.hex is byte-identical - the
    gap lived in comments and two macros no code reads.
    [e0001.c, e0001.h, main.c]
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2026-08-21 store: re-annotate E0003 and complete its supply nets
    E0003-000001.kicad_sch: designators re-annotated (J8/J9 to J1/J2;
    U1 PCA9306, U2 TLV70018, U3 AS7331, U4 AS7343; passives renumbered).
    C1/C2 10 uF, C3 4.7 uF, C7 100 nF added at the AS7343 VDD pin.
    U3 VDDA/VDDD tied to +3.3V; they sat on an isolated net carrying only
    R4, which ERC reported as an undriven power input.
    PWR_FLAG on +3.3V, GND, GNDA and the TLV70018 input node.
    ERC 0 errors, 16 isolated-label warnings on unused header signals.
    [E0003-000001.kicad_sch]
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2026-08-22 store: package KiCad design sources by layer, add the E0003 layout
    ADR-0017: add decision 19 (design sources package per document layer),
    the -src code-legend row, and alternative I.
    store: replace 16 loose .kicad_* objects with 8 -S-src.zip / -D-src.zip
    packages across E0001-000003, E0002-000001, E0003-000001, E0006-000001.
    store: add the E0003 layout, its .kicad_dru (U1/U3 0.5 mm pitch) and -D.png;
    raise the U3 silk reference to 1 mm in the board and the vendor footprint.
    REGISTRY.md, CONTRIBUTING.md: design-source section and packing procedure.
    spec/M02-LIGHT: record the layout state in §13; LICENSES: SnapEDA edit list.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
    [E0001-000003.kicad_pcb, E0001-000003.kicad_sch, E0002-000001.kicad_pcb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]
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2026-08-24 firmware: clear latched I2C flags, read SCD41 identity while stopped
    i2c.c: clear AF and ADDR entering start() and after every failed transfer;
    re-init when the bus holds BUSY without MSL; fail a NACKed write on AF
    rather than two timeouts; clear POS on the aborted i2c_read_reg16 phase.
    scd4x.c: read serial and temperature offset in scd4x_configure(), while
    periodic measurement is stopped; the accessors report what it read.
    A stale AF made start() abort a good address phase and latch ADDR, after
    which every start() -- i2c_probe() included -- reported an address phase
    that never ran: on E0002, node 97 published heartbeat only with all three
    sensors reported present.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
    [i2c.c]
2026-08-24 firmware: report SCD41 ASC state in the boot log
    scd4x.c: cache what the ASC branch found and whether it persisted;
    scd4x_asc_status() replaces the out_persisted parameter no caller used.
    sensors.c: print that state on the U3 probe line.
    ASC found on again after this firmware has configured the device means the
    persist is not sticking, and that spends one of the EEPROM's 2000 cycles on
    every boot. E0002 reads "already off".
    [sensors.c]
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2026-08-24 M01-CLIMATE: publish U2's gas channel as an R(T) sweep
    dsdl: GasResistance.2.0 carries setpoints and resistances index-for-index.
    Major bump, not the minor one 1.0 anticipated — an extent is shared across a
    major version and 1.0's 32 bytes hold no sweep at any array capacity.
    bme68x.c/.h: trigger() and meas_duration_ms() take the setpoint; 0 keeps the
    hotplate dark.
    sensors.c: four setpoints back to back per scan, published as one message;
    pressure and the secondary T/RH come from the step that opens the sweep.
    cmake/dsdl.cmake: the generation stamp now depends on the DSDL sources, so a
    new type regenerates instead of failing on a missing header.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
    [sensors.c]
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2026-08-24 firmware: stop asserting an unsynchronized timestamp, report sensor health
    cyphal: cyphal_timestamp_usec() returns 0 = UNKNOWN. Every message carried
    micros64(), which is that node's uptime, not a network base — node 96 stamped
    1378 s and node 97 stamped 62 s for the same instant, and the type reserves 0
    for exactly that. One seam for a future uavcan.time.Synchronization master.
    cyphal: publish uavcan.node.port.List every 10 s at OPTIONAL priority;
    cyphal_declare_publishers() takes the personality's subjects. TX queue 24 -> 40
    frames and heap 4 -> 8 KiB: the 172-byte list is 25 frames, so the push failed,
    and tx_push() discards the result so it failed silently.
    cyphal: heartbeat health is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
    [i2c.c, sensors.c]
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2026-08-24 M05-SAFETY: health, diagnostics and a command surface
    sensors.c: consecutive read failures per device drive health — CAUTION when
    U2 fails, since metering is why E0006 exists, ADVISORY for U1. Population at
    boot, health transitions and door/leak state changes publish
    uavcan.diagnostic.Record.
    sensors.c: vendor commands 1 = zero the energy accumulator, 2 = report the raw
    leak ADC sample. Both serve recorded residuals: the accumulator is volatile and
    LEAK_WET_THRESHOLD is provisional.
    s0.c: s0_reset().
    spec §9: the command surface, diagnostics, timestamps, port.List and the health
    rule.
    [sensors.c]
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2026-08-24 M05-SAFETY: make LeakStatus.valid report the conversion
    leak.c: leak_sample() replaces leak_is_wet() and leak_sample_raw(). One call
    yields the state and the raw count from one excitation pulse, and returns false
    when the ADC conversion does not complete -- the data register then holds a
    stale value, and comparing it against a threshold invents a leak state.
    sensors.c: valid carries that result. The TODO claiming the excitation was not
    driven was stale; leak.c has gated it all along.
    spec §9: leak validity and the door failure direction. §10: V5 and V6 executed.
    §11: O-74, the threshold margin -- dry reads 4068...4095 and no wet count exists.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
    [sensors.c]
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2026-08-25 Sweep the Node-ID and unique_id claims onto ADR-0027
    Nine places cited ADR-0005 d6 or ADR-0007 as the last word.
    Specs M01/M02/M05: the Node-ID row no longer presents an instance value as a
    property of the module class, and stops mirroring other modules' assignments.
    firmware README, cyphal.h, node.h, registry.c: cite ADR-0027; the README's
    "ATECC supplies the instance identity" conflated unique_id with Node-ID.
    igrow.hex unchanged.
    [registry.c]
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2026-08-26 Provision the Node-ID from carrier flash (ADR-0027)
    - common/platform/flash.c: STM32F4 sector erase/program, RAM-resident, reloads the IWDG itself.
    - common/carrier/identity.c: Node-ID record (magic/version/id/CRC) in flash sector 11.
    - ldscripts: FLASH 896K, sector 11 reserved as IDENTITY, .RamFunc copied to SRAM.
    - node.h, registry.c: personality drops node_id; 127 is IGROW_NODE_ID_UNPROVISIONED.
    - registers.c: uavcan.node.id mutable + persistent, commits to flash, effective at restart.
    - cyphal.c: ADVISORY health for unprovisioned or unresolved; diagnostic while a commit is pending.
    - main.c: telemetry requires a provisioned identity and a resolved personality.
    - ADR-0027 d10: constant re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
    [identity.c, main.c]
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2026-08-26 Report a device that vanished, not just one that answers wrongly
    - m01_climate/sensors.c, m05_safety/sensors.c: track devices seen present; absent-after-seen is a fault.
    - both: the health diagnostic names faulted or vanished devices.
    - M01 spec section 10, M05 spec section 10: health counts a vanished device.
    - M01 spec O-75: the I2C wedge this exposed is open, cause unidentified.
    - store/E0001-000001-F.hex, -F-src.zip: rebuilt.
    [sensors.c]
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2026-08-29 Build the ADR-0029 boot chain
    Bootloader in sectors 0-3; the application links to a slot base, so it is
    built once per A/B slot and a release is three images. mkimage.py wraps
    each in the 512-byte image header -- one VTOR alignment unit, so the
    vector table follows it directly.
    The bootloader reads the update-state log in sector 4, spends a trial
    attempt before running the image, falls back to the other slot on a CRC
    failure, and halts instead of reset-looping when neither boots. Download
    and signature verification are not built.
    [identity.c]
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2026-08-29 Build the ADR-0029 download path
    The bootloader is now a Cyphal node: it runs the same skeleton as the
    application, reads the artifact from whoever issued the update command
    with uavcan.file.Read, and verifies ECDSA P-256 over SHA-256 before the
    slot is marked bootable on trial. micro-ecc (BSD-2) is vendored for the
    curve; SHA-256 is ours and carries a self-test.
    Neither key is in the repository: -DIGROW_SIGNING_KEY signs, and
    -DIGROW_VERIFY_KEY_HEX compiles the public half into the bootloader.
    Without them images build and flash over SWD but no node accepts one.
    [main.c, update.c]
2026-08-29 Show an update on the core-board LED, and report the version
    PB2 is the only LED visible with a module mounted: dark while the
    application runs, on when the bootloader joins the bus, one flicker per
    block through the transfer, steady through verification.
    The d11 diagnostic now carries major.minor and reaches the bus -- the
    restart goes through the skeleton's flush instead of resetting with the
    frame still queued.
    [e0001.c, e0001.h, main.c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]
2026-08-29 Correct the core-board LED polarity to active-high
    Measured on the bench: PB2 high lights the blue LED, low is dark. The
    assumption in the other direction had it lit while the application ran and
    dark through an update -- the inverse of what it is for.
    [e0001.h]
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2026-08-29 Report a refused update on the bus, not only on the console
    Found by testing the two refusal paths: an image that failed verification
    was correctly refused and the previous image kept running, but the node
    said nothing to the gateway -- the diagnostic was queued and then dropped
    by the hand-over into the application.
    Every abandoned update now names its reason as a diagnostic and flushes
    before returning. ADR-0029 d11 asks for the verification result; a refusal
    is one.
    [update.c]
2026-08-29 Make signing a decision the release has to state
    Three ways the key handling could go wrong silently, all closed:
    release.sh builds in its own directory, so a release no longer resets the
    keys cached in the one a developer flashes from -- that left unsigned
    images and a keyless bootloader behind, and flashing one disarmed a node.
    It now takes --key or --unsigned; omitting both is an error, and --key
    derives the public half rather than trusting a second input to match.
    CMake refuses half a key pair. The bootloader says at boot whether it
    holds a verification key at all.
    [main.c]
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2026-09-07 M02: publish UV-A validity from modulator 2 alone
    STATUS2's ALS_DIGITAL_SATURATION is device-wide and names no modulator.
    Folding it into the UV sample marked every reading invalid on E0003-000001,
    where the photopic and IR modulators saturate indoors while modulator 2 sits
    near the bottom of its range. Validity now rests on modulator 2's own flags.
    Init also stops the engine and writes MEAS_MODE0 and both AGC patterns rather
    than inheriting them: nothing resets this part across an MCU restart, and an
    active AGC owns the gain registers. The bench command gains a register dump.
    [sensors.c]
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2026-09-07 M02: select U4 before the autorange write
    publish_all() left the bus switch on U3 after the UV read and then called
    autorange(), so as7343_set_range() wrote the AS7343's ENABLE, ATIME and
    ASTEP into the TSL2585 -- both parts answer at 0x39. The TSL2585 came up
    correctly and was overwritten a second later, and the AS7343 never received
    a range change while s_atime/s_again recorded that it had.
    Measured after the fix: every TSL2585 register holds what init wrote,
    modulator 2 runs at the programmed 1024x, and the spectral counts answer to
    the autorange. Corrects the AGC attribution in the tsl2585 init comments.
    [sensors.c]
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2026-09-10 Store: the tempering unit's case follows the case convention
    The housing went in as a loose STEP under a new slug, which matched none
    of the four cases already in the store. It is now a package on the same
    form they use, holding the STEP alone.
    [E0012-000001-D-case-bottom.stp]
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2026-09-17 Schematic: E0011 A01-CLIMATE, first capture
    Two DRV8262 stages, single H-bridge for the main stack and dual for the
    subcooler and reheater; a PCA9685 for the module's own drive lines. Six
    comparator sections and a quad AND gate carry T2-T5 into both sleep
    inputs. Reverse-polarity block at the +24 V entry. Header B 2x10, and a
    2x14 expansion header for the signal reserve. ERC 0 / 0.
    DRV8262DDW and PCA9685PW enter industrygrow.kicad_sym.
    [E0011-000001.kicad_sch]
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2026-09-22 E0011: board outline and placement
    The outline carries four corner mounting holes and a carrier footprint
    centred between two connector strips. Signal headers occupy one long edge
    and power terminals the other, their wire entry facing off the board. Each
    driver sits at the carrier band's lower edge above its bulk capacitor,
    output inductor and terminal. Interlock sensing, the fan drives and the
    spare thermistor channels occupy the signal strip. Connectivity is
    unchanged and silkscreen clearance is clean.
    [E0011-000001.kicad_pcb]
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2026-10-04 Mechanical: HS1 bottom corrected
    [HS1-bottom.stp]
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

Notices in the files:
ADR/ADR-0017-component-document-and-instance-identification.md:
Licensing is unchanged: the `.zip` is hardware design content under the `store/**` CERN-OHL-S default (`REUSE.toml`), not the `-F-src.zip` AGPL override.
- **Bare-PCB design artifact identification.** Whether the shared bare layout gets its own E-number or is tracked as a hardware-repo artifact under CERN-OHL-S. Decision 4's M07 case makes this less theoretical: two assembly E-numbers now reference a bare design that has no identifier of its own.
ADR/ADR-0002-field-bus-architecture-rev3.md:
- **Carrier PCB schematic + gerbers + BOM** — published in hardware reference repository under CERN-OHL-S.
